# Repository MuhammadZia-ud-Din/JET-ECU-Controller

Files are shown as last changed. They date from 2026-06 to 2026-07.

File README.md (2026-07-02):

# JET ECU Controller

A custom Engine Control Unit (ECU) for monitoring and controlling a small JET engine during ground testing.

The system consists of STM32F103C8T6 firmware and a Python GUI dashboard connected over serial.

---

## Repository Structure

```
JET ECU Firmware/                    — Active firmware (STM32CubeIDE + FreeRTOS)
├── Core/Src/main.c                  — All application code (FreeRTOS tasks, serial protocol)
├── Core/Inc/main.h                  — Pin definitions
└── JET_ECU_Project_Documentation.docx — Full project documentation

JET ECU GUI/
└── ECU GUI.py                       — Python dashboard GUI

JET_ECU_V1.0/
└── JET_ECU_V1.0.ino                 — Arduino firmware
```

---

## Firmware

The active firmware runs on **FreeRTOS (CMSIS-RTOS v2)** with four concurrent tasks:

| Task | Priority | Rate | Role |
|---|---|---|---|
| ThrottleTask | AboveNormal | 200 ms | RC PWM reading, spike filter, 0–100% output |
| VoltageTask | Normal | ~756 ms | Battery voltage (256-sample avg), MCU temperature |
| FETReportTask | Normal | 200 ms | Reports all 6 FET states over serial |
| SerialRxTask | High | Event | Parses incoming commands from GUI |

Built with **STM32CubeIDE**. All user code is inside `USER CODE BEGIN / END` sections and survives CubeMX regeneration.

---

## Features

- **Dual thermocouple monitoring** — EGT (exhaust) and intake temperature via MAX31855
- **Battery voltage** — 12-bit ADC, 256-sample averaging, two-point linear calibration (5V/24V anchors), up to 26V
- **RC throttle input** — GPIO pulseIn via DWT counter, default calibration 1540–2000 µs → 0–100%
- **ESC PWM output** — throttle % mapped 1:1 onto a 1000–2000 µs pulse on PA10 (TIM1_CH3) at 50 Hz, driving a BLDC ESC
- **6-channel FET control** — Toggle individual FETs or use ALL HIGH / ALL LOW group control
- **MCU temperature** — On-chip die temperature sensor
- **Python GUI** — Left: 2×2 gauge grid (Throttle, Tachometer, ESC PWM Output, Battery Voltage). Right: individually-boxed TC1/TC2/MCU temperature graphs, 4×2 FET grid, serial log. Plus Emergency Stop and USB-TTL disconnect detection.

---

## Hardware

| Item | Detail |
|---|---|
| MCU | STM32F103C8T6 (Blue Pill), 64 MHz |
| Thermocouple amplifiers | MAX31855 × 2 (SPI1 + SPI2) |
| RC receiver | R12DS — CH3 PWM signal to PA0 (GPIO Input) |
| ESC output | PA10 (TIM1_CH3), 1000–2000 µs pulse @ 50 Hz, mapped from RC throttle |
| Serial link | UART2 (PA2/PA3) via USB-TTL adapter at 115200 baud |
| Battery input | Up to ~26V via 39K + 5.6K voltage divider on PA1 |

---

## GUI Requirements

```
pip install pyserial
```

Python 3 with `tkinter` (included in standard Python install). No internet required at runtime.

---

## Quick Start

1. Open `JET ECU Firmware/` in STM32CubeIDE and flash to the Blue Pill
2. Connect USB-TTL adapter to PA2 (TX) and PA3 (RX), share GND
3. If powering the board from the battery/supply rather than USB, run a **dedicated, always-connected ground wire** from the battery's negative terminal straight to the Blue Pill's GND pin — independent of the USB-TTL cable. Without it, unplugging/replugging the USB-TTL adapter can leave GND floating momentarily and cause serial glitches (also required for accurate battery voltage sensing — see Calibration in the project docs).
4. Run `ECU GUI.py`
5. Select COM port, set baud to 115200, click CONNECT
6. Throttle works immediately — use **SET RC** only if you need to fine-tune to your transmitter

---

## Serial Protocol

| Direction | Format | Example |
|---|---|---|
| Firmware → PC | `THR: xxx` | `THR: 75` |
| Firmware → PC | `PWM: xxx` | `PWM: 75`  (ESC output %, mirrors THR) |
| Firmware → PC | `TC1: x.x C  \|  TC2: x.x C` | `TC1: 245.5 C  \|  TC2: 32.1 C` |
| Firmware → PC | `Raw: xxxx V_ADC: x.xxx V V_BATT: xx.xx V` | `V_BATT: 23.85 V` |
| Firmware → PC | `MCU: xx.x C` | `MCU: 24.4 C` |
| Firmware → PC | `FET:x,x,x,x,x,x` | `FET:1,0,0,0,0,0` |
| PC → Firmware | `FETn:1` / `FETn:0` | `FET3:1` |
| PC → Firmware | `FET_ALL:1` / `FET_ALL:0` | All 6 FETs HIGH or LOW |
| PC → Firmware | `CAL_CENTER` / `CAL_FULL` / `CAL_RESET` | RC throttle calibration |

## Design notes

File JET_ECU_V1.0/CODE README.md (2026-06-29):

# JET ECU V1.0

Firmware for a custom Engine Control Unit (ECU) designed to monitor and control a JET engine during testing. Built for the STM32F103C8T6 (Blue Pill).

---

## Hardware

| Component | Details |
|---|---|
| MCU | STM32F103C8T6 (Blue Pill) |
| Serial | UART2 via TTL adapter (PA2=TX, PA3=RX) at 115200 baud — bidirectional |

---

## Pin Map

| Function | Pin | Notes |
|---|-----|---|
| Thermocouple 1 SCK | PA5 | EGT / Exhaust — MAX31855 software SPI |
| Thermocouple 1 SO | PA6 | |
| Thermocouple 1 CS | PB0 | |
| Thermocouple 2 SCK | PB13 | Intake / Ambient — MAX31855 software SPI |
| Thermocouple 2 SO | PB14 | |
| Thermocouple 2 CS | PB12 | |
| Battery Voltage | PA1 | Voltage divider: 39K + 5.6K, max input ~24V |
| RC PWM Input | PA0 | R12DS CH3 signal wire — standard 1000–2000µs PWM |
| RPM Sensor | PC14 | Future pulse-counting input (not yet implemented) |
| FET 1 | PB6 | |
| FET 2 | PB5 | |
| FET 3 | PB9 | |
| FET 4 | PB8 | |
| FET 5 | PB4 | |
| FET 6 | PB7 | |
| MCU Temperature | Internal | ADC channel 16 — die temperature sensor |

---

## Libraries

- `Adafruit_MAX31855` — thermocouple temperature reading
- `HardwareSerial` — UART2 serial communication

---

## What is Implemented

### Battery Voltage (PA1)
- 12-bit ADC with 64-sample averaging for noise reduction
- Voltage divider scaling: 39K + 5.6K resistors
- Calibration factor (0.9905) applied to correct ~1% gain error from VDDA/resistor tolerance
- Accuracy: within ±0.05V across 16V–24V input range
- Reported every 500ms

### Thermocouple Reading (TC1 + TC2)
- TC1 reads exhaust gas temperature (EGT) via MAX31855
- TC2 reads intake / ambient temperature via MAX31855
- NaN fault handling — returns 0.0 on sensor fault or open circuit
- Reported every 250ms

### FET Outputs (PB4–PB9)
- All 6 FET pins configured as outputs, driven LOW at startup (safe state)
- Accepts real-time toggle commands from the GUI over serial: `FET1:1` / `FET1:0`
- Reports all 6 FET states every 200ms: `FET:1,0,0,0,0,0`

### RC Throttle Input (PA0)
- Reads standard RC PWM signal from R12DS receiver CH3 pin
- Pulse width range: 1000–2000µs mapped to 0–100% throttle
- Spike rejection: rejects any reading that jumps more than 400µs from last valid
- Hold-last-valid: maintains last known value; resets to 0 only after 500ms signal loss
- Calibration via GUI: SET RC wizard captures center and full-throttle positions
- Reported every 200ms as `THR: xxx`

### MCU Internal Temperature
- Reads the STM32F103 on-chip die temperature sensor (ADC channel 16)
- Calibrated V25 = 1.58V, slope = 4.3 mV/°C
- Accuracy: ±2–3°C (sensor varies chip-to-chip; value reflects die temperature, not ambient)
- Reported every 1000ms

---

## Serial Interface

Connect a USB-TTL adapter to PA2 (TX) and PA3 (RX) at **115200 baud**.

### Output (firmware → PC)

```
JET ECU V1.0 Ready
TC1: 245.5 C  |  TC2: 32.1 C
Raw: 3741    V_ADC: 3.014 V    V_BATT: 24.01 V
THR: 75
MCU: 24.4 C
FET:1,0,0,0,0,0
```

### Input (PC → firmware)

| Command | Action |
|---|---|
| `FET1:1` | Turn FET 1 HIGH |
| `FET1:0` | Turn FET 1 LOW |
| `FET2:1` … `FET6:0` | Same for FETs 2–6 |
| `CAL_CENTER` | Sample RC center position (hold stick at center first) |
| `CAL_FULL` | Sample RC full throttle position (push stick to full first) |
| `CAL_RESET` | Clear calibration — throttle returns 0 until recalibrated |

---

## GUI Dashboard

A Python-based ground station (`JET ECU GUI/ECU GUI.py`) connects over serial and displays all channels in real time:

- **THROTTLE gauge** — RC input 0–100%
- **TACHOMETER gauge** — RPM sensor 0–50,000 (PC14, pending implementation)
- **Battery voltage** circular gauge
- **Vertical thermometers** for TC1 (EGT), TC2 (Intake), and MCU temperature
- **FET panel** — live status LEDs and toggle buttons (layout: 1/3/5 top, 2/4/6 bottom)
- **SET RC / RESET RC** calibration buttons
- Serial log with CLEAR button

---

## What is Pending

- [ ] RPM sensor (PC14) — pulse counting via external interrupt, output `RPM: xxx`

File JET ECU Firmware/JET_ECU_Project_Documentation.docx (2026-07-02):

JET ECU Controller

Project Documentation — Design, Implementation & Status

Date: July 02, 2026

1. Project Overview

The JET ECU Controller is a custom Engine Control Unit (ECU) designed to monitor and control a small JET (turbine) engine during laboratory ground testing. The system connects a microcontroller-based hardware unit to a PC-based graphical dashboard over a serial link, enabling real-time telemetry display and manual actuation of engine components.

The project targets a low-cost, self-contained solution that can run fully offline on any Windows/Linux/macOS PC with Python installed — no cloud connectivity or proprietary software required.

2. Requirements & Goals

2.1 Functional Requirements

ID | Requirement
FR-01 | Monitor two thermocouple temperatures (exhaust EGT + intake ambient) in real time.
FR-02 | Monitor battery / supply voltage up to 26 V with ±0.1 V accuracy.
FR-03 | Read RC receiver throttle PWM signal and map it to 0–100 % throttle.
FR-04 | Control six high-side FET outputs individually or all at once (ALL HIGH / ALL LOW) from the GUI.
FR-05 | Display MCU die temperature as a system health indicator.
FR-06 | Transmit all sensor data to the PC GUI over UART at 115200 baud.
FR-07 | Accept individual FET toggle commands, group FET commands, and RC calibration commands from the GUI.
FR-08 | Provide a PC-side dashboard with live gauges — no internet required.
FR-09 | RC throttle must work immediately on power-on using hardcoded default calibration values.

2.2 Non-Functional Requirements

- Real-time telemetry update rates: throttle every 200 ms, voltage every 500 ms, temperature every 250 ms.
- Spike rejection on RC throttle: reject any single reading that jumps more than 400 µs from the last valid reading.
- Hold-last-valid on RC signal loss: maintain last known throttle value; reset to 0 % only after 500 ms of no signal.
- Voltage measurement must survive power-on noise (raw-count zero-offset calibration).
- GUI must work fully offline with standard Python 3 and pyserial.
- All firmware code must survive CubeMX code regeneration (placed in USER CODE sections only).

3. Hardware

3.1 Components

Component | Part / Type | Notes
Microcontroller | STM32F103C8T6 | Blue Pill board, 72 MHz max, 64 MHz used (HSI × PLL)
Thermocouple Amp ×2 | MAX31855 | SPI interface, ±2 °C accuracy, open-circuit detection
RC Receiver | R12DS | CH3 PWM output, 1000–2000 µs pulse width at 50 Hz
Serial Adapter | USB-TTL (CP210x) | Connects PA2/PA3 to PC USB port at 115200 baud
FET Driver ×6 | High-side FETs | GPIOB-driven, active-HIGH control signal
Voltage Divider | 39 kΩ + 5.6 kΩ | Scales battery input (up to ~26 V) to ADC range (0–3.3 V)

3.2 Pin Map

Pin | Function | Details
PA0 | RC PWM Input | R12DS CH3 signal — digital GPIO_Input NOPULL, pulseIn via DWT cycle counter
PA1 | Battery Voltage ADC | 39 kΩ + 5.6 kΩ divider, ADC1 CH1, 12-bit, DMA circular
PA2 | UART2 TX | Serial output to PC (115200 baud)
PA3 | UART2 RX | Serial input from PC (115200 baud, DMA Normal mode + IDLE detection)
PA5 | TC1 SCK | MAX31855 #1 clock (EGT / Exhaust), SPI1
PA10 | ESC PWM Output | TIM1_CH3, 1000–2000 µs pulse @ 50 Hz, mapped 1:1 from RC throttle %
PA6 | TC1 SO | MAX31855 #1 data out, SPI1
PB0 | TC1 CS | MAX31855 #1 chip select
PB13 | TC2 SCK | MAX31855 #2 clock (Intake / Ambient), SPI2
PB14 | TC2 SO | MAX31855 #2 data out, SPI2
PB12 | TC2 CS | MAX31855 #2 chip select
PB4 | FET 5 | High-side FET #5 control, active HIGH
PB5 | FET 2 | High-side FET #2 control, active HIGH
PB6 | FET 1 | High-side FET #1 control, active HIGH
PB7 | FET 6 | High-side FET #6 control, active HIGH
PB8 | FET 4 | High-side FET #4 control, active HIGH
PB9 | FET 3 | High-side FET #3 control, active HIGH
PC14 | RPM Sensor Input | Future: pulse-counting via external interrupt (not yet implemented)
INT | MCU Temperature | ADC1 CH16 internal temperature sensor — die temperature

4. Software Architecture

The firmware runs on FreeRTOS (CMSIS-RTOS v2) with four application tasks running concurrently. The PC dashboard is a single-file Python script using tkinter for the GUI and pyserial for communication.

4.1 Firmware Tasks

Task | Priority | Period | Responsibility
ThrottleTask | AboveNormal | 200 ms | Reads RC PWM via GPIO polling (pulseIn_us), applies spike filter and hold-last-valid logic, maps to 0–100 % throttle, drives the ESC PWM output (TIM1_CH3), sends THR: and PWM: output.
VoltageTask | Normal | ~756 ms | Averages 256 ADC DMA samples (1 ms apart) for battery voltage, applies two-point linear calibration. Reads MCU die temp every ~1512 ms.
FETReportTask | Normal | 200 ms | Reads current GPIO state of all 6 FET pins and reports FET:x,x,x,x,x,x over serial.
SerialRxTask | High | Event | Waits on UART IDLE semaphore, parses incoming commands (FETn:x, FET_ALL:x, CAL_CENTER, CAL_FULL, CAL_RESET), executes and responds.

4.2 FreeRTOS Configuration

Parameter | Value | Notes
Heap size | 8192 bytes | Set via .ioc — sufficient for 4 tasks + mutexes + semaphores
Application task stack | 1024 bytes (256×4) | Each of the 4 tasks — sized for snprintf + HAL calls
Tick rate | 1000 Hz (1 ms) | Standard FreeRTOS tick
UART TX method | Blocking HAL_UART_Transmit + mutex | DMA TX caused deadlocks; blocking is safe and simple
UART RX method | DMA Normal + IDLE detection | HAL_UARTEx_ReceiveToIdle_DMA; half-transfer interrupt disabled; semaphore on each line received
ADC1 DMA | Circular, 2-channel scan | Continuously fills adc_buf[0]=battery, adc_buf[1]=MCU temp
RC timing | DWT cycle counter (64 cycles = 1 µs) | Measures pulse width without a hardware timer; 50 ms timeout per call
TIM1 (ESC PWM) | PSC=63, ARR=19999 | 1 MHz counter, 20 ms/50 Hz period; CCR value in µs directly matches RC/ESC pulse convention

5. Implemented Features

5.1 Battery Voltage Measurement

- Voltage divider: 39 kΩ (R1) + 5.6 kΩ (R2) scales battery voltage to ADC input range (max ~26 V).
- ADC1 CH1 (PA1) reads in 12-bit DMA circular mode alongside MCU temperature on CH16.
- 256-sample averaging with 1 ms delay between samples (increased from an initial 64) — halves report-to-report ADC jitter with no added lag, since each report is computed independently (no memory carried between reports, so a real voltage change still shows on the next report).
- Two-point direct linear interpolation between two known (raw, voltage) points — no forced "0 V" anchor, since that raw value drifts whenever the sense line’s ground reference changes (e.g. powering the board from the battery supply vs. from USB):
- VBATT_RAW_LO = 770 at VBATT_MV_LO = 5000 mV (low anchor point)
- VBATT_RAW_HI = 3710 at VBATT_MV_HI = 24000 mV (high anchor point)
- Formula: V_batt (mV) = MV_LO + (raw − RAW_LO) × (MV_HI − MV_LO) / (RAW_HI − RAW_LO)
- VBATT_RAW_FLOOR = 250 → raw ≤ 250 is treated as no battery connected → reports 0.00 V
- Anchored on the widest available voltage separation (5 V / 24 V) for best accuracy — validated against 10 V and 20 V measurements, both within ±0.02 V of actual.
- Serial output: Raw: 3608 V_ADC: 2.907 V V_BATT: 24.00 V (every ~756 ms)
- Calibration constants in one #define block in firmware — easy to update per board.

5.2 RC Throttle Input

- RC receiver R12DS CH3 output connected to PA0 as digital GPIO_Input (no pull resistor).
- PA0 must NOT be configured as ADC input — RC PWM is a 3.3–5 V square wave, not an analog signal.
- pulseIn_us() function uses the DWT cycle counter (64 cycles = 1 µs) to time the HIGH pulse.
- 50 ms timeout per measurement call — covers the full 20 ms RC period plus FreeRTOS jitter.
- Spike filter: reading rejected if it differs from last valid by more than 400 µs.
- Hold-last-valid: maintains last good value; resets to center only after 500 ms of signal loss.
- Default calibration values (stored in firmware, active from first power-on):
- rc_pw_min = 1540 µs → 0 % throttle reference (measured neutral position on this board)
- rc_pw_max = 2000 µs → 100 % throttle reference (full throw)
- Throttle works immediately on power-on without requiring user calibration.
- GUI-driven recalibration (optional — use if defaults do not match your transmitter):
- CAL_CENTER → averages 10 pulses at center position → overwrites 0 % reference in RAM
- CAL_FULL → averages 10 pulses at full throw → overwrites 100 % reference in RAM
- CAL_RESET → clears RAM calibration to 0/0; throttle reads 0 % until SET RC is run again
- Values outside calibrated range are clamped (below min = 0 %, above max = 100 %).
- RAM calibration is lost on power cycle — defaults (1540/2000) are restored automatically.
- Serial output: THR: 75 (every 200 ms, integer 0–100)

5.3 ESC PWM Output (BLDC Motor Control)

- Drives an ESC (Electronic Speed Controller) for a BLDC motor via a standard RC-style PWM signal on PA10 (TIM1_CH3).
- TIM1 configured for a 1 MHz counter (Prescaler=63) with a 20000-count period (Period/ARR=19999) → 20 ms period = 50 Hz, the standard RC/ESC signal rate.
- Because the counter runs at 1 MHz, the CCR (pulse) register value in counts equals the pulse width in microseconds directly — no extra scaling math needed.
- ThrottleTask maps the same 0–100 % throttle value used for THR: onto the pulse width: pwm_us = 1000 + (throttle × 1000 / 100), giving the standard 1000 µs (0 %) to 2000 µs (100 %) ESC convention.
- PWM output starts at boot (1000 µs, armed-and-idle) via HAL_TIM_PWM_Start(), before the RTOS scheduler takes over — the ESC sees a valid idle signal immediately rather than a floating pin.
- Firmware reports the mapped percentage every 200 ms: PWM: 75 (mirrors THR: since the mapping is currently 1:1; reported separately so the GUI/log reflect the actual ESC command being sent, not just the RC input reading).

5.4 FET Outputs

- Six FET control pins on GPIOB (FET1=PB6, FET2=PB5, FET3=PB9, FET4=PB8, FET5=PB4, FET6=PB7).
- All pins initialised LOW (safe off state) at startup.
- Individual control: GUI sends FETn:1 or FETn:0 (n = 1–6) to toggle any single FET.
- Group control: GUI sends FET_ALL:1 (all 6 FETs HIGH) or FET_ALL:0 (all 6 FETs LOW).
- Firmware confirms group commands: responds FET_ALL:1 or FET_ALL:0 over UART.
- Firmware reports all six states every 200 ms: FET:1,0,0,0,0,0
- GUI FET panel layout — 4 rows × 2 columns:
- Row 0: FET 1 | FET 2 Row 1: FET 3 | FET 4 Row 2: FET 5 | FET 6
- Row 3: ALL HIGH (green LED) | ALL LOW (red LED)
- Each cell shows: coloured LED (green=ON, red=OFF), label, state text, and action button.
- ALL HIGH / ALL LOW buttons update all six GUI LEDs immediately on click.

5.5 Thermocouple Reading (TC1 + TC2)

- Two MAX31855 thermocouple amplifiers connected via hardware SPI (SPI1 and SPI2).
- TC1 on SPI1 (PA5/PA6/PB0) monitors exhaust gas temperature (EGT).
- TC2 on SPI2 (PB13/PB14/PB12) monitors intake / ambient temperature.
- Open-circuit / fault detection: NaN returned on fault → reported as 0.0 °C.
- Serial output: TC1: 245.5 C | TC2: 32.1 C (every 250 ms)

5.6 MCU Internal Temperature

- STM32F103 internal temperature sensor on ADC1 CH16, sampled in the same DMA scan as battery voltage.
- Calibration: V25 = 1.58 V, slope = 4.3 mV/°C (empirically measured; datasheet typical: V25=1.43 V).
- Accuracy: ±2–3 °C — useful as a thermal health indicator for the MCU, not for ambient temperature.
- Serial output: MCU: 24.4 C (every 1000 ms)

5.7 PC Dashboard (Python GUI)

- Single Python file (ECU GUI.py), no installation beyond Python 3 + pyserial.
- Connects to any available COM port at 115200 baud; auto-detects and parses all telemetry lines.
- Two-column layout — left: 2×2 gauge grid; right: stacked temperature / FET / log panel.
- Left column, row 0: THROTTLE gauge | TACHOMETER gauge
- Left column, row 1: ESC PWM OUTPUT gauge | BATTERY VOLTAGE gauge
- All four are 290 px needle dials with a digital value readout on the dial face, in the blank 90° wedge below the pivot where the sweep and tick labels leave genuinely empty space — avoids the value overlapping the needle, and needs no separate box or border.
- Right column, top: TC1 / TC2 / MCU temperature graphs, each in its own bordered card, evenly justified across the column width (equal-weighted grid columns) so there is no empty gap.
- Right column, middle: FET panel, 4 rows × 2 columns (FET1/FET2, FET3/FET4, FET5/FET6, ALL HIGH/ALL LOW). Each cell: coloured LED, label, HIGH/LOW state text, action button on the right.
- Right column, bottom: serial log — confined to the right column's width (not the full window), height reduced to keep the overall window height close to the left gauge column's height.
- Emergency Stop button (top-right of the connection bar) — forces all 6 FETs LOW immediately, independent of the ALL LOW button in the FET panel, always visible regardless of scroll position.
- USB-TTL disconnect detection — if the serial adapter is physically removed while connected, the reader thread detects the read failure and automatically resets the GUI to DISCONNECTED (status, button, all gauges, all FET states) instead of freezing on stale data.
- RC calibration: SET RC button → step-by-step wizard (center position → full throw).
- RESET RC: clears RAM calibration; user must redo SET RC to restore custom mapping.
- All displays reset to zero on disconnect (manual or automatic).

6. Serial Protocol

Connection: 115200 baud, 8N1, UART2 (PA2 = TX, PA3 = RX) via USB-TTL adapter.

6.1 Firmware → PC Telemetry

Message | Rate | Description
JET ECU V1.0 Ready | Once on boot | Boot confirmation banner
TC1: 245.5 C | TC2: 32.1 C | Every 250 ms | Thermocouple temperatures in °C
Raw: 3741 V_ADC: 3.014 V V_BATT: 24.01 V | Every 500 ms | Raw ADC count, divider output, calibrated battery voltage
THR: 75 | Every 200 ms | RC throttle percentage (0–100, integer)
PWM: 75 | Every 200 ms | ESC PWM output percentage (mirrors THR — the actual mapped ESC command)
MCU: 24.4 C | Every ~1512 ms | MCU die temperature in °C
FET:1,0,0,0,0,0 | Every 200 ms | State of FET1–FET6 (1=ON, 0=OFF, comma-separated)

6.2 PC → Firmware Commands

Command | Action
FET1:1 | Turn FET 1 ON (drive HIGH)
FET1:0 | Turn FET 1 OFF (drive LOW)
FET2:1 … FET6:0 | Same for FETs 2 through 6
FET_ALL:1 | Set ALL six FETs HIGH simultaneously. Firmware responds: FET_ALL:1
FET_ALL:0 | Set ALL six FETs LOW simultaneously. Firmware responds: FET_ALL:0
CAL_CENTER | Sample 10 RC pulses at stick center; sets 0 % throttle reference in RAM. Responds: CAL_CENTER:1540
CAL_FULL | Sample 10 RC pulses at full throw; sets 100 % throttle reference in RAM. Responds: CAL_FULL:2000
CAL_RESET | Clear RAM calibration to 0/0; throttle reads 0 % until SET RC is run. Responds: CAL_RESET:OK

7. Calibration Procedures

7.1 Battery Voltage Calibration

Required whenever the supply/ground path changes (e.g. switching between powering the board from USB vs. from the battery/supply directly) — the raw ADC baseline shifts with the ground reference even though the underlying voltage-to-raw-count slope stays the same. Requires a known-accurate bench supply or multimeter.

- Step 1: Power the board exactly as it will be used during testing (this affects the ground reference).
- Step 2: Apply a known low voltage (e.g. 5.00 V) to the battery input. Note the "Raw: xxxx" value → LO point.
- Step 3: Apply a known high voltage (e.g. 24.00 V). Note the "Raw: xxxx" value → HI point.
- Step 4: Use the widest voltage separation available — it minimizes calibration error.
- Step 5: Set VBATT_RAW_LO / VBATT_MV_LO and VBATT_RAW_HI / VBATT_MV_HI from those two readings.
- Step 6: Rebuild and flash. Cross-check against one or two intermediate voltages to confirm accuracy.

Board measurements (2026-07-02, direct-supply powered, re-checked): 5.00 V → Raw 770, 24.00 V → Raw 3710. Anchored on the widest available separation (5 V/24 V).

7.2 Grounding for Reliable UART Operation

When the board is powered by the battery/supply instead of USB, the USB-TTL adapter's GND wire may be the only path tying the PC's ground and the board's ground together. Unplugging/replugging the TTL adapter in that condition can leave GND floating for a moment during the connector mating transition, which can glitch the UART RX line or briefly reset the MCU.

- Run a separate, permanently-connected ground wire from the battery's negative terminal directly to the Blue Pill's GND pin, independent of whichever wire is currently supplying power to the board.
- This ground wire should remain connected at all times, regardless of which power source (USB or battery) is active, or whether the USB-TTL adapter is plugged in.
- With a dedicated ground path in place, the TTL adapter's TX/RX/GND can be safely unplugged and replugged without disturbing the board's ground reference.
- This is the same underlying requirement as accurate battery voltage sensing (Section 5.1) — both the ADC divider and the UART need a ground reference that does not depend on which cable is currently plugged in.

7.3 RC Throttle Calibration (optional — GUI-driven)

Firmware ships with default values rc_pw_min = 1540 µs (0 %) and rc_pw_max = 2000 µs (100 %). These match the measured neutral and full-throw positions on this board and allow the throttle to function immediately without user calibration. Use SET RC only if the defaults do not match your transmitter or after running RESET RC.

- Step 1: Power on the RC transmitter and receiver. Confirm signal is present (THR: will start printing).
- Step 2: Hold the throttle stick at the centre/idle position.
- Step 3: In the GUI, click SET RC → OK at Step 1 prompt. Firmware averages 10 pulses → stores as 0 % reference.
- Step 4: Push the throttle stick to full throttle position.
- Step 5: Click OK at Step 2 prompt. Firmware averages 10 pulses → stores as 100 % reference.
- Step 6: THR: value now tracks stick position from 0 to 100.
- Step 7: Click RESET RC at any time to clear the RAM calibration; throttle returns 0 % until SET RC is re-run.

Note: SET RC and RESET RC operate on RAM only — values are lost on power cycle. Firmware defaults (1540 / 2000) are automatically restored at next boot.

8. Issues Encountered and Resolutions

Issue: UART not printing anything

Root Cause: DMA transmit + binary semaphore pattern caused deadlock when task stacks were too small. Stack overflow corrupted the semaphore state.

Resolution: Replaced DMA TX with blocking HAL_UART_Transmit protected by a mutex. Increased all application task stacks from 512 bytes to 1024 bytes.

Issue: RC calibration command stuck — firmware froze on CAL_CENTER

Root Cause: UART RX DMA was configured in Circular mode. In this mode the DMA transfer size accumulates across commands, so subsequent commands were not parsed correctly and the firmware appeared to hang.

Resolution: Changed UART2 RX DMA to Normal mode in the .ioc configuration. The DMA restarts cleanly after each line received via the IDLE callback.

Issue: Battery voltage fluctuating wildly on power-on (0 – 3 V at 0 V actual)

Root Cause: Firmware was reading a single DMA ADC sample capturing high-frequency noise. Additionally the ADC had a zero-offset (~0.15–0.17 V at 0 V actual input).

Resolution: Implemented 64-sample averaging with 1 ms delay between samples. Added a raw-count zero-offset calibration constant (VBATT_RAW_ZERO = 190) to clamp the noise floor to 0.00 V.

Issue: Battery voltage showing ~0.38 V at 0 V input after initial calibration attempt

Root Cause: Initial calibration constants were derived from single-sample (non-averaged) measurements. After enabling 64-sample averaging the ADC baseline shifted — zero-offset raw count changed from ~55 to ~183, making old constants invalid.

Resolution: Switched to a raw-count two-point calibration formula that bypasses the resistor-divider intermediate calculation entirely. Constants updated from board measurements: VBATT_RAW_ZERO = 190, VBATT_RAW_CAL = 3923 at 24.00 V.

Issue: RC throttle always reading 0 % (THR: 0) regardless of stick position

Root Cause: PA0 was configured as ADC input. ADC showed ~0.3 V constant because it was averaging the 7.5 % duty-cycle PWM (1500 µs HIGH out of 20 ms period), not seeing the individual pulses.

Resolution: Removed ADC2 from .ioc; reconfigured PA0 as GPIO_Input. Implemented pulseIn_us() using DWT cycle counter to time HIGH pulses directly. Timeout increased to 50 ms to account for FreeRTOS scheduling jitter. Confirmed 1530–1950 µs signal via debug print. Throttle now maps correctly 0–100 %.

Issue: RC throttle stuck at 0 % after CAL_CENTER (THR: 0 with valid signal)

Root Cause: sample_rc_pw() was using 20 samples with a tight valid-range check; some samples failed the 900–2100 µs gate, causing the average to come out 0, setting rc_pw_min = 0 and rc_pw_max = 0.

Resolution: Reduced to 10 samples (faster, less chance of gating failure); verified pulseIn_us returns valid values via debug print. Throttle mapping now works correctly across full range.

Issue: Battery voltage showing a constant ~1.6 V offset after switching to direct-supply power (24.00 V actual read as 22.40 V; 20.00 V actual read as 18.40 V — same absolute gap at both points, confirming an offset, not a gain error)

Root Cause: The old VBATT_RAW_ZERO/VBATT_RAW_CAL constants were calibrated while the board was powered via USB. Powering the Blue Pill directly from the battery/supply instead changed the ADC sense line’s ground reference, shifting the raw ADC baseline for every voltage by a constant amount — the "0 V anchor" the old formula relied on no longer matched reality.

Resolution: Replaced the zero-anchored formula with a direct two-point linear interpolation between two real, non-extrapolated measurements (5.00 V → Raw 678, 24.00 V → Raw 3608), which is immune to this kind of ground-reference shift since it does not assume any particular raw value corresponds to exactly 0 V. Validated against 10 V/20 V measurements — both within ±0.02 V of actual.

Issue: Residual ~0.10 V report-to-report fluctuation in V_BATT even after correct calibration

Root Cause: The 64-sample block average still let through some ADC/supply noise between reports; a first attempt at fixing it with a 10-report moving average smoothed the display but made it react to genuine voltage changes ~5.6 s slower — rejected as unacceptable lag.

Resolution: Increased the per-report oversampling window from 64 to 256 samples instead. This halves jitter via the same block average (√(256/64) ≈ 2×) but carries no memory between reports, so a real voltage change still shows up on the very next report — no added lag, unlike the moving-average approach.

Issue: FET outputs turn HIGH then immediately revert to LOW on their own — happens on every individual FET and on FET_ALL:1 identically; no MCU reboot banner in the log

Root Cause: Firmware code was verified clean (no rogue GPIO write path resets the pins, individual and group commands share correct, identical logic, pin mapping between write and readback is consistent). Root-caused via staged testing: worked correctly on USB-TTL power alone, and on battery power with the TTL still connected — but failed specifically after unplugging and replugging the TTL adapter while the board ran on battery power. With no separate ground wire between the battery and the board, the TTL's GND wire was the only path tying the PC's ground and the board's ground together; unplugging it left GND floating momentarily, and the connector pins not mating simultaneously on replug caused a transient on RX/GND that glitched the UART or briefly reset the MCU (which re-runs the boot-time GPIO init that forces all FET pins LOW).

Resolution: Diagnosed root cause; recommended fix is a dedicated, permanently-connected ground wire from the battery's negative terminal directly to the Blue Pill's GND pin, independent of the USB-TTL cable — see Section 7.2. Same class of fix as the battery-voltage ground-reference issue above, applied to the UART connection instead of the ADC sense line. Pending field confirmation that the dedicated ground wire eliminates the issue.

9. Current Status

9.1 Completed

- ✓ Battery voltage — 256-sample averaged, two-point linear calibration (5V/24V anchors), accurate to ±0.02 V
- ✓ RC throttle — GPIO pulseIn, default cal (1540/2000 µs), spike filter, hold-last-valid, 0–100 % output
- ✓ ESC PWM output — throttle % mapped 1:1 onto TIM1_CH3 (PA10), 1000–2000 µs @ 50 Hz, drives a BLDC ESC
- ✓ Six FET outputs — individual toggle + ALL HIGH / ALL LOW group control
- ✓ FET group commands — FET_ALL:1 and FET_ALL:0 iterate all 6 pins in firmware
- ✓ MCU die temperature — internal ADC channel, reported every ~1512 ms
- ✓ Thermocouple TC1 + TC2 (MAX31855) — temperature reporting every 250 ms via SPI
- ✓ UART telemetry — all channels on UART2, 115200 baud, DMA RX + blocking TX
- ✓ FreeRTOS multi-task firmware — four concurrent tasks with mutex-protected UART
- ✓ PC Python GUI — 2×2 left gauge grid (Throttle/Tach/PWM/Voltage), individually-boxed temp graphs, 4×2 FET panel, Emergency Stop, USB-TTL disconnect detection, RC calibration wizard, serial log

9.2 Pending

- ○ RPM Sensor (PC14) — Pulse-counting via external interrupt on PC14. Output format: RPM: xxxxx at 1000 ms intervals. GUI tachometer gauge is already implemented and waiting for this data.
- ○ Battery voltage — hardware-level ripple — If jitter is still noticeable after the 256-sample software averaging, the remaining cause is likely real analog ripple/noise on the PA1 sense line rather than something software averaging alone can remove. A small filter capacitor (100 nF–1 µF) from PA1 to GND would filter it at the source.
- ○ Thermocouple port to CubeIDE — TC1/TC2 SPI reading is currently only in the original Arduino firmware. The CubeIDE firmware has SPI1/SPI2 configured but the MAX31855 read routine has not yet been ported to the STM32 HAL SPI API.
- ○ FET outputs reverting to LOW on battery power — Root cause diagnosed as a missing dedicated ground wire between the battery and the board (see Section 8 issue and Section 7.2). Fix identified but not yet confirmed in the field — verify the boot banner no longer reprints and FETs hold state after adding the ground wire.

10. Key Values Reference

Parameter | Value | Notes
RC PWM default min (0 %) | 1540 µs | Hardcoded firmware default — measured neutral on this board
RC PWM default max (100 %) | 2000 µs | Hardcoded firmware default — standard RC full throw
RC pulse valid range | 900–2100 µs | Readings outside this range are discarded by ThrottleTask
RC spike filter | 400 µs max jump | Per sample; rejects mechanical bounce and EMI spikes
RC signal-loss timeout | 500 ms | After this, throttle resets to hold-last-valid then 0 %
RC pulseIn timeout | 50 ms | Covers 20 ms RC period + FreeRTOS scheduling jitter margin
CAL_CENTER / CAL_FULL samples | 10 pulses averaged | RAM-only; lost on power cycle; defaults restored at boot
VBATT_RAW_LO / VBATT_MV_LO | 770 / 5000 mV | Low calibration anchor (measured, direct-supply powered)
VBATT_RAW_HI / VBATT_MV_HI | 3710 / 24000 mV | High calibration anchor (measured, direct-supply powered)
VBATT_RAW_FLOOR | 250 | Raw ADC count at/below which output clamps to 0.00 V (no battery)
Voltage divider ratio | 44600 / 5600 ≈ 7.96× | 39 kΩ + 5.6 kΩ; max readable ~26 V
ADC resolution | 12-bit (0–4095) | VDDA = 3.3 V; 1 LSB ≈ 0.806 mV
ADC averaging | 256 samples × 1 ms | Total settling time ~256 ms per voltage reading
ESC PWM pulse range | 1000–2000 µs | 0–100 % throttle mapped 1:1 onto standard RC/ESC pulse convention
ESC PWM frequency | 50 Hz (20 ms period) | TIM1: PSC=63 → 1 MHz counter, ARR=19999 → 20 ms period
ESC PWM idle-at-boot | 1000 µs | Set before RTOS scheduler starts — ESC sees a valid signal immediately
MCU clock | 64 MHz | HSI oscillator × PLL; DWT counter: 64 cycles = 1 µs
MCU V25 | 1.58 V | Internal temp sensor V25 (empirically measured; datasheet typical = 1.43 V)
MCU temp slope | 4.3 mV / °C | Internal temperature sensor slope
UART baud rate | 115200 | 8N1, no flow control
FreeRTOS heap | 8192 bytes | Total FreeRTOS heap (set in .ioc)
Task stack size | 1024 bytes | Each of the 4 application tasks

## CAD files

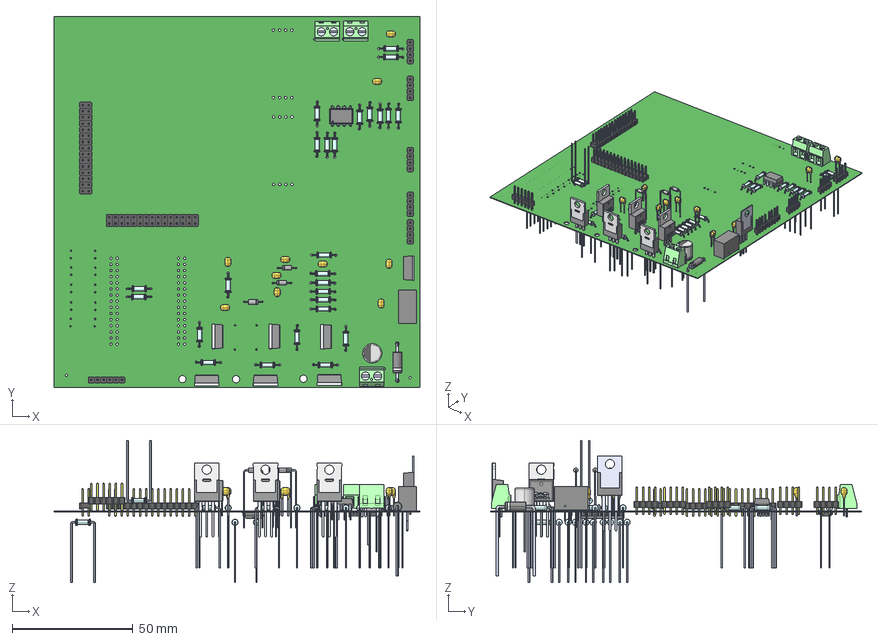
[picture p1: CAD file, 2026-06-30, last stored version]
Faizan Khan Design/JET ENGINE ECU for BLDC motor STM 32f405/JET ECU ver_2.1.step
151.6 x 153.8 x 59.0 mm
MFP-25BRD52-220R x 38
Base014 x 2
Pino029 x 2
Pino030 x 2
Base x 8
Pino1 x 2
Pino2 x 2
Base001 x 8
Pino003 x 8
Pino004 x 3
Base002 x 8
Pino006 x 2
Pino005 x 3
Base003 x 8
Pino008 x 2
Pino007 x 2
Base004 x 3
Pino009 x 2
Pino010 x 2
Base005 x 3
Pino012 x 2
Pino011 x 2
Base006 x 2
Pino013 x 2
Pino014 x 2
Base007 x 2
Pino015 x 2
Pino016 x 2
Base008 x 2
Pino017 x 2
Pino018 x 2
Base009 x 2
Pino019 x 2
Pino020 x 2
Base010 x 2
Pino021 x 2
Pino022 x 2
Base011 x 2
Pino023 x 2
Pino024 x 2
Base012 x 2
Pino025 x 2
Pino026 x 2
Base013 x 2
Pino027 x 2
Pino028 x 2
Body001 (Mirror #1) x 8
XY-plane x 24
X-axis x 24
PG-TO220-3-904_Z8B00198139_V06_3D x 6
Pino x 6
Pino001 x 6
Pino002 x 6
282837-2--3DModel-STEP-269445 x 3
Diode 1N4148 x 3
1N5408
C315C470J1G5TA x 10

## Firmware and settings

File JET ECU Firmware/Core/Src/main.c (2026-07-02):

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
/* Includes ------------------------------------------------------------------*/
#include "main.h"
#include "cmsis_os.h"

/* USER CODE BEGIN Includes */
#include <string.h>
#include <stdio.h>
/* USER CODE END Includes */

/* USER CODE BEGIN PD */

/* ── Battery voltage two-point calibration (raw ADC count based) ─────────────
   Direct linear interpolation between two known (raw, voltage) points —
   no forced "0 V" anchor, since that raw value drifts whenever the sense
   line's ground reference changes (e.g. powering the board from the
   battery supply vs. from USB). Anchoring on two real mid/high-range
   measurements instead is immune to that shift.

   HOW TO RECALIBRATE (if the supply/ground path changes again):
     1. Apply a known low voltage, note "Raw: xxxx" → LO point.
     2. Apply a known high voltage, note "Raw: xxxx" → HI point.
        (Use the widest voltage separation you can — it minimizes error.)
     3. Set the four constants below from those two readings.

   Board measurements (2026-07-02, direct-supply powered, re-checked):
     5.00 V → Raw 770  |  24.00 V → Raw 3710
   Anchored on the widest available separation (5 V / 24 V).                */
#define VBATT_RAW_LO     770UL   /* raw count at VBATT_MV_LO actual voltage */
#define VBATT_MV_LO     5000UL   /* actual voltage at the low calibration point (mV) */
#define VBATT_RAW_HI    3710UL   /* raw count at VBATT_MV_HI actual voltage */
#define VBATT_MV_HI    24000UL   /* actual voltage at the high calibration point (mV) */
#define VBATT_RAW_FLOOR  250UL   /* below this, treat as no battery connected → 0.00 V */

/* USER CODE END PD */

ADC_HandleTypeDef hadc1;
DMA_HandleTypeDef hdma_adc1;

SPI_HandleTypeDef hspi1;
SPI_HandleTypeDef hspi2;
DMA_HandleTypeDef hdma_spi1_rx;
DMA_HandleTypeDef hdma_spi2_rx;

TIM_HandleTypeDef htim1;

UART_HandleTypeDef huart2;
DMA_HandleTypeDef hdma_usart2_rx;
DMA_HandleTypeDef hdma_usart2_tx;

/* Definitions for defaultTask */
osThreadId_t defaultTaskHandle;
const osThreadAttr_t defaultTask_attributes = {
  .name = "defaultTask",
  .stack_size = 128 * 4,
  .priority = (osPriority_t) osPriorityNormal,
};
/* USER CODE BEGIN PV */

/* ── ADC DMA buffer ─────────────────────────────────────────────────────────
   [0] = Battery voltage raw (PA1 / CH1)
   [1] = MCU temperature raw (internal TEMPSENSOR / CH16)
   DMA runs in circular mode — just read these two values anytime.           */
static uint16_t adc_buf[2];

/* ── RC PWM input (PA0, GPIO polling via DWT — matches Arduino pulseIn) ─── */
static uint32_t rc_pw_min        = 1535U;     /* default 0 % position (µs)  */
static uint32_t rc_pw_max        = 1950U;     /* default 100 % position (µs) */
static uint32_t rc_last_pw       = 1500;      /* last accepted pulse width   */
static uint32_t rc_last_valid_ms = 0;         /* kernel tick of last valid PW */
#define RC_MAX_STEP   400U                    /* max µs jump between samples  */
#define RC_TIMEOUT_MS 500U                    /* signal-loss timeout          */

/* ── UART RX ────────────────────────────────────────────────────────────── */
#define RX_BUF_SIZE 64
static uint8_t rx_dma_buf[RX_BUF_SIZE];      /* DMA target (circular)       */
static char    rx_cmd[RX_BUF_SIZE];          /* command copied on IDLE event */

/* ── FET GPIO pin array (index 0=FET1 … 5=FET6, all GPIOB) ────────────── */
static const uint16_t FET_PIN[6] = {
    FET_1_Pin, FET_2_Pin, FET_3_Pin,
    FET_4_Pin, FET_5_Pin, FET_6_Pin
};

/* ── RTOS synchronisation objects ──────────────────────────────────────── */
static osMutexId_t     uart_tx_mutex;   /* one sender at a time              */
static osSemaphoreId_t uart_cmd_sem;    /* signalled by UART RX IDLE ISR     */

/* ── Task handles ───────────────────────────────────────────────────────── */
static osThreadId_t throttleTaskHandle;
static osThreadId_t voltageTaskHandle;
static osThreadId_t fetReportTaskHandle;
static osThreadId_t serialRxTaskHandle;

/* USER CODE END PV */

void SystemClock_Config(void);
static void MX_GPIO_Init(void);
static void MX_DMA_Init(void);
static void MX_ADC1_Init(void);
static void MX_TIM1_Init(void);
static void MX_USART2_UART_Init(void);
static void MX_SPI1_Init(void);
static void MX_SPI2_Init(void);
void StartDefaultTask(void *argument);

/* USER CODE BEGIN PFP */
static void     uart_send(const char *str);
static uint32_t pulseIn_us(GPIO_TypeDef *port, uint16_t pin, uint32_t timeout_us);
static uint32_t sample_rc_pw(uint8_t n);
void ThrottleTask(void *arg);
void VoltageTask(void *arg);
void FETReportTask(void *arg);
void SerialRxTask(void *arg);
/* USER CODE END PFP */

/**
  * @brief  The application entry point.
  * @retval int
  */
int main(void)
{

  /* MCU Configuration--------------------------------------------------------*/

  /* Reset of all peripherals, Initializes the Flash interface and the Systick. */
  HAL_Init();

  /* Configure the system clock */
  SystemClock_Config();

  /* Initialize all configured peripherals */
  MX_GPIO_Init();
  MX_DMA_Init();
  MX_ADC1_Init();
  MX_TIM1_Init();
  MX_USART2_UART_Init();
  MX_SPI1_Init();
  MX_SPI2_Init();
  /* USER CODE BEGIN 2 */

  /* ADC self-calibration — recommended for F103 before first DMA conversion */
  HAL_ADCEx_Calibration_Start(&hadc1);

  /* Start continuous ADC→DMA: fills adc_buf[0]=BATT, [1]=MCU_TEMP forever  */
  HAL_ADC_Start_DMA(&hadc1, (uint32_t *)adc_buf, 2);

  /* Enable DWT cycle counter — 32-bit, 64 MHz, wraps every ~67 s. */
  CoreDebug->DEMCR |= CoreDebug_DEMCR_TRCENA_Msk;
  DWT->CYCCNT = 0;
  DWT->CTRL  |= DWT_CTRL_CYCCNTENA_Msk;

  /* ESC PWM output — TIM1_CH3 (PA10), 1 MHz counter (PSC=63, ARR=19999)
     gives a 20 ms (50 Hz) period with the CCR value directly in µs, so it
     matches the standard 1000–2000 µs RC/ESC pulse convention. Starts at
     1000 µs (0 % throttle / ESC armed-and-idle) before the RTOS takes over. */
  HAL_TIM_PWM_Start(&htim1, TIM_CHANNEL_3);
  __HAL_TIM_SET_COMPARE(&htim1, TIM_CHANNEL_3, 1000U);

  /* Start UART2 RX DMA with IDLE detection — fires callback on each command  */
  HAL_UARTEx_ReceiveToIdle_DMA(&huart2, rx_dma_buf, RX_BUF_SIZE);
  __HAL_DMA_DISABLE_IT(huart2.hdmarx, DMA_IT_HT); /* suppress half-transfer */

  /* Boot banner — blocking TX before RTOS scheduler starts                   */
  HAL_UART_Transmit(&huart2, (uint8_t *)"JET ECU V1.0 Ready\r\n", 20, 100);

  /* USER CODE END 2 */

  /* Init scheduler */
  osKernelInitialize();

  /* USER CODE BEGIN RTOS_MUTEX */
  uart_tx_mutex = osMutexNew(NULL);
  /* USER CODE END RTOS_MUTEX */

  /* USER CODE BEGIN RTOS_SEMAPHORES */
  uart_cmd_sem = osSemaphoreNew(1, 0, NULL);   /* binary, starts locked */
  /* USER CODE END RTOS_SEMAPHORES */

  /* USER CODE BEGIN RTOS_TIMERS */
  /* start timers, add new ones, ... */
  /* USER CODE END RTOS_TIMERS */

  /* USER CODE BEGIN RTOS_QUEUES */
  /* add queues, ... */
  /* USER CODE END RTOS_QUEUES */

  /* Create the thread(s) */
  /* creation of defaultTask */
  defaultTaskHandle = osThreadNew(StartDefaultTask, NULL, &defaultTask_attributes);

  /* USER CODE BEGIN RTOS_THREADS */
  /* 256×4=1024-byte stacks: snprintf+uart_send+FreeRTOS context save need ~500 bytes */
  static const osThreadAttr_t thr_attr = { .name="ThrottleTask",  .stack_size=256*4, .priority=osPriorityAboveNormal };
  static const osThreadAttr_t volt_attr= { .name="VoltageTask",   .stack_size=256*4, .priority=osPriorityNormal      };
  static const osThreadAttr_t fet_attr = { .name="FETReportTask", .stack_size=256*4, .priority=osPriorityNormal      };
  static const osThreadAttr_t rx_attr  = { .name="SerialRxTask",  .stack_size=256*4, .priority=osPriorityHigh        };

  throttleTaskHandle  = osThreadNew(ThrottleTask,  NULL, &thr_attr);
  voltageTaskHandle   = osThreadNew(VoltageTask,   NULL, &volt_attr);
  fetReportTaskHandle = osThreadNew(FETReportTask, NULL, &fet_attr);
  serialRxTaskHandle  = osThreadNew(SerialRxTask,  NULL, &rx_attr);
  /* USER CODE END RTOS_THREADS */

  /* USER CODE BEGIN RTOS_EVENTS */
  /* add events, ... */
  /* USER CODE END RTOS_EVENTS */

  /* Start scheduler */
  osKernelStart();

  /* We should never get here as control is now taken by the scheduler */

  /* Infinite loop */
  /* USER CODE BEGIN WHILE */
  while (1)
  {
    /* USER CODE END WHILE */

    /* USER CODE BEGIN 3 */
  }
  /* USER CODE END 3 */
}

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
/* USER CODE BEGIN 4 */

/* ── UART helpers ─────────────────────────────────────────────────────────
   uart_send() acquires a mutex (one sender at a time) then calls the
   blocking HAL_UART_Transmit.  At 115200 baud the longest message is ~4 ms;
   FreeRTOS will time-slice other tasks during that window.  The blocking
   approach is simpler and more reliable than DMA TX + semaphore because it
   avoids the race where DMA completes before osSemaphoreAcquire is reached
   and the risk of semaphore corruption from a stack overflow in the task.    */

static void uart_send(const char *str)
{
    uint16_t len = (uint16_t)strlen(str);
    if (len == 0) return;
    osMutexAcquire(uart_tx_mutex, osWaitForever);
    HAL_UART_Transmit(&huart2, (uint8_t *)str, len, HAL_MAX_DELAY);
    osMutexRelease(uart_tx_mutex);
}

/* Called from DMA IRQ on IDLE line or buffer full.
   Copies received bytes to rx_cmd, signals SerialRxTask, re-arms DMA.       */
void HAL_UARTEx_RxEventCallback(UART_HandleTypeDef *huart, uint16_t Size)
{
    if (huart->Instance == USART2 && Size > 0 && Size < RX_BUF_SIZE) {
        memcpy(rx_cmd, rx_dma_buf, Size);
        rx_cmd[Size] = '\0';
        osSemaphoreRelease(uart_cmd_sem);
        HAL_UARTEx_ReceiveToIdle_DMA(&huart2, rx_dma_buf, RX_BUF_SIZE);
        __HAL_DMA_DISABLE_IT(huart2.hdmarx, DMA_IT_HT);
    }
}

/* ── RC PWM — direct GPIO polling, equivalent to Arduino pulseIn() ────────
   Waits for a HIGH pulse on PA0 within timeout_us microseconds.
   Uses DWT cycle counter (enabled in USER CODE BEGIN 2, 64 cycles = 1 µs).
   A shared deadline across all three phases means total wait ≤ timeout_us.   */

static uint32_t pulseIn_us(GPIO_TypeDef *port, uint16_t pin, uint32_t timeout_us)
{
    uint32_t deadline = DWT->CYCCNT + timeout_us * 64U;
    /* if pin is already HIGH, wait for it to go LOW first (skip current pulse) */
    while (HAL_GPIO_ReadPin(port, pin) == GPIO_PIN_SET)
        if ((int32_t)(DWT->CYCCNT - deadline) >= 0) return 0;
    /* wait for rising edge */
    while (HAL_GPIO_ReadPin(port, pin) == GPIO_PIN_RESET)
        if ((int32_t)(DWT->CYCCNT - deadline) >= 0) return 0;
    uint32_t rise = DWT->CYCCNT;
    /* measure until falling edge */
    while (HAL_GPIO_ReadPin(port, pin) == GPIO_PIN_SET)
        if ((int32_t)(DWT->CYCCNT - deadline) >= 0) return 0;
    return (DWT->CYCCNT - rise) / 64U;
}

/* ── RC calibration helper ────────────────────────────────────────────────
   Directly measures n pulses (25 ms timeout each) — matches Arduino samplePW().
   Called from SerialRxTask; blocks up to n × (25 ms + 50 ms) ≈ 1.5 s.       */

static uint32_t sample_rc_pw(uint8_t n)
{
    uint32_t sum = 0; uint8_t cnt = 0;
    for (uint8_t i = 0; i < n; i++) {
        uint32_t pw = pulseIn_us(GPIOA, GPIO_PIN_0, 25000U);
        if (pw >= 900U && pw <= 2100U) { sum += pw; cnt++; }
        osDelay(50);
    }
    return cnt ? (sum / cnt) : 0U;
}

/* ── Task: ThrottleTask (200 ms) ──────────────────────────────────────────
   Spike filter: reject any jump > RC_MAX_STEP µs.
   Signal-loss: if no valid pulse for RC_TIMEOUT_MS, output 0 %.
   Output: THR: xxx\r\n                                                       */

void ThrottleTask(void *arg)
{
    char buf[32];
    for (;;) {
        uint32_t pw = pulseIn_us(GPIOA, GPIO_PIN_0, 50000U);

        if (pw >= 900U && pw <= 2100U) {
            uint32_t delta = (pw > rc_last_pw) ? (pw - rc_last_pw) : (rc_last_pw - pw);
            if (delta <= RC_MAX_STEP || rc_last_pw == 1500U) {
                rc_last_pw       = pw;
                rc_last_valid_ms = osKernelGetTickCount();
            }
        }

        if ((osKernelGetTickCount() - rc_last_valid_ms) > RC_TIMEOUT_MS)
            rc_last_pw = 1500U;

        uint32_t thr = 0;
        if (rc_pw_min < rc_pw_max) {
            if (rc_last_pw <= rc_pw_min) {
                thr = 0;
            } else if (rc_last_pw >= rc_pw_max) {
                thr = 100;
            } else {
                thr = (rc_last_pw - rc_pw_min) * 100U / (rc_pw_max - rc_pw_min);
            }
        }

        snprintf(buf, sizeof(buf), "THR: %lu\r\n", thr);
        uart_send(buf);

        /* ESC PWM output — throttle % mapped directly to the 1000–2000 µs
           RC/ESC pulse convention (0 % = 1000 µs, 100 % = 2000 µs).        */
        uint32_t pwm_us = 1000U + (thr * 1000U) / 100U;
        __HAL_TIM_SET_COMPARE(&htim1, TIM_CHANNEL_3, pwm_us);
        snprintf(buf, sizeof(buf), "PWM: %lu\r\n", thr);
        uart_send(buf);

        osDelay(200);
    }
}

/* ── Task: VoltageTask (500 ms batt, 1000 ms MCU temp) ───────────────────
   ADC DMA buffer read directly — no lock needed (16-bit atomic read, and
   small timing skew is irrelevant at these sample rates).

   Integer arithmetic throughout — avoids needing -u _printf_float linker flag.

   Battery divider: R1=39kΩ, R2=5.6kΩ → ratio = 44600/5600
   Calibration factor: 9905/10000 (≈ 0.9905)
   All voltages in mV, formatted with manual decimal split.

   MCU temp: V25=1580 mV (chip-calibrated), slope=4.3 mV/°C
   temp×10 = ((1580 - vt_mv) × 100) / 43 + 250                              */

void VoltageTask(void *arg)
{
    char    buf[64];
    uint8_t mcu_cnt = 0;

    for (;;) {
        /* 256-sample average with 1 ms between reads — 4x the original 64-sample
           window, which halves report-to-report ADC jitter (~sqrt(4)) without
           adding any cross-report lag (no memory carried between reports, so a
           real voltage change still shows up on the very next report).
           Total: 256 ms sampling + osDelay(500) ≈ 756 ms per voltage report.  */
        uint32_t sum = 0;
        for (uint16_t i = 0; i < 256; i++) {
            sum += adc_buf[0];
            osDelay(1);
        }
        uint16_t raw  = (uint16_t)(sum / 256U);

        /* V_ADC at divider output — kept for display and future diagnostics */
        uint32_t vadc = ((uint32_t)raw * 3300U) / 4095U;

        /* Battery voltage via direct two-point linear interpolation between
           VBATT_RAW_LO/MV_LO and VBATT_RAW_HI/MV_HI (see USER CODE BEGIN PD).
           raw ≤ VBATT_RAW_FLOOR means no battery connected → clamp to 0.    */
        uint32_t vbat = 0;
        if (raw > VBATT_RAW_FLOOR) {
            int32_t v = (int32_t)VBATT_MV_LO
                      + ((int32_t)raw - (int32_t)VBATT_RAW_LO)
                        * ((int32_t)VBATT_MV_HI - (int32_t)VBATT_MV_LO)
                        / ((int32_t)VBATT_RAW_HI - (int32_t)VBATT_RAW_LO);
            vbat = (v > 0) ? (uint32_t)v : 0;
        }

        snprintf(buf, sizeof(buf),
                 "Raw: %u\tV_ADC: %lu.%03lu V\tV_BATT: %lu.%02lu V\r\n",
                 raw,
                 vadc / 1000UL, vadc % 1000UL,
                 vbat / 1000UL, (vbat % 1000UL) / 10UL);
        uart_send(buf);

        /* MCU internal temperature — every second (every 2nd cycle) */
        if (++mcu_cnt >= 2) {
            mcu_cnt = 0;
            uint16_t rt   = adc_buf[1];
            int32_t vt_mv = ((int32_t)rt * 3300L) / 4095L;
            int32_t t10   = (((1580L - vt_mv) * 100L) / 43L) + 250L;
            snprintf(buf, sizeof(buf), "MCU: %ld.%ld C\r\n",
                     t10 / 10L, (t10 < 0 ? -t10 : t10) % 10L);
            uart_send(buf);
        }

        osDelay(500);
    }
}

/* ── Task: FETReportTask (200 ms) ─────────────────────────────────────────
   Reads actual GPIO output state via HAL_GPIO_ReadPin (reads ODR, atomic).
   Output: FET:x,x,x,x,x,x\r\n                                               */

void FETReportTask(void *arg)
{
    char buf[24];
    for (;;) {
        snprintf(buf, sizeof(buf), "FET:%u,%u,%u,%u,%u,%u\r\n",
                 (unsigned)HAL_GPIO_ReadPin(GPIOB, FET_PIN[0]),
                 (unsigned)HAL_GPIO_ReadPin(GPIOB, FET_PIN[1]),
                 (unsigned)HAL_GPIO_ReadPin(GPIOB, FET_PIN[2]),
                 (unsigned)HAL_GPIO_ReadPin(GPIOB, FET_PIN[3]),
                 (unsigned)HAL_GPIO_ReadPin(GPIOB, FET_PIN[4]),
                 (unsigned)HAL_GPIO_ReadPin(GPIOB, FET_PIN[5]));
        uart_send(buf);
        osDelay(200);
    }
}

/* ── Task: SerialRxTask (event-driven, high priority) ─────────────────────
   Waits on uart_cmd_sem released by HAL_UARTEx_RxEventCallback.

   Commands:
     FETn:v        set FET n (1-6) to v (0|1)
     CAL_CENTER    sample 20 readings at stick center → sets rc_pw_min
     CAL_FULL      sample 20 readings at full throw   → sets rc_pw_max
     CAL_RESET     clear calibration, throttle returns 0 until recal          */

void SerialRxTask(void *arg)
{
    char cmd[RX_BUF_SIZE];
    char resp[32];

    for (;;) {
        osSemaphoreAcquire(uart_cmd_sem, osWaitForever);

        strncpy(cmd, rx_cmd, RX_BUF_SIZE - 1);
        cmd[RX_BUF_SIZE - 1] = '\0';

        /* Strip CR/LF */
        for (int i = 0; cmd[i]; i++)
            if (cmd[i] == '\r' || cmd[i] == '\n') { cmd[i] = '\0'; break; }

        /* FET_ALL:v — set all 6 FETs HIGH (v=1) or LOW (v=0) */
        if (strncmp(cmd, "FET_ALL:", 8) == 0) {
            GPIO_PinState st = (cmd[8] == '1') ? GPIO_PIN_SET : GPIO_PIN_RESET;
            for (int i = 0; i < 6; i++)
                HAL_GPIO_WritePin(GPIOB, FET_PIN[i], st);
            uart_send(cmd[8]=='1' ? "FET_ALL:1\r\n" : "FET_ALL:0\r\n");
        }
        /* FETn:v — set single FET */
        else if (cmd[0]=='F' && cmd[1]=='E' && cmd[2]=='T' &&
            cmd[3] >= '1' && cmd[3] <= '6' && cmd[4] == ':') {
            int n = cmd[3] - '1';
            HAL_GPIO_WritePin(GPIOB, FET_PIN[n],
                              cmd[5] == '1' ? GPIO_PIN_SET : GPIO_PIN_RESET);
        }
        /* CAL_CENTER */
        else if (strncmp(cmd, "CAL_CENTER", 10) == 0) {
            uint32_t pw = sample_rc_pw(10);
            rc_pw_min = pw; rc_pw_max = 0;
            snprintf(resp, sizeof(resp), "CAL_CENTER:%lu\r\n", pw);
            uart_send(resp);
        }
        /* CAL_FULL */
        else if (strncmp(cmd, "CAL_FULL", 8) == 0) {
            uint32_t pw = sample_rc_pw(10);
            rc_pw_max = pw;
            snprintf(resp, sizeof(resp), "CAL_FULL:%lu\r\n", pw);
            uart_send(resp);
        }
        /* CAL_RESET */
        else if (strncmp(cmd, "CAL_RESET", 9) == 0) {
            rc_pw_min = 0U; rc_pw_max = 0U; rc_last_pw = 1500U;
            uart_send("CAL_RESET:OK\r\n");
        }
    }
}

/* USER CODE END 4 */

/* USER CODE BEGIN Header_StartDefaultTask */
/**
  * @brief  Function implementing the defaultTask thread.
  * @param  argument: Not used
  * @retval None
  */
/* USER CODE END Header_StartDefaultTask */
void StartDefaultTask(void *argument)
{
  /* USER CODE BEGIN 5 */
  for (;;)
      osDelay(1000);
  /* USER CODE END 5 */
}

/**
  * @brief  Period elapsed callback in non blocking mode
  * @note   This function is called  when TIM3 interrupt took place, inside
  * HAL_TIM_IRQHandler(). It makes a direct call to HAL_IncTick() to increment
  * a global variable "uwTick" used as application time base.
  * @param  htim : TIM handle
  * @retval None
  */
void HAL_TIM_PeriodElapsedCallback(TIM_HandleTypeDef *htim)
{
  if (htim->Instance == TIM3)
  {
    HAL_IncTick();
  }
}

/**
  * @brief  This function is executed in case of error occurrence.
  * @retval None
  */
void Error_Handler(void)
{
  /* USER CODE BEGIN Error_Handler_Debug */
  /* User can add his own implementation to report the HAL error return state */
  __disable_irq();
  while (1)
  {
  }
  /* USER CODE END Error_Handler_Debug */
}

#ifdef  USE_FULL_ASSERT
/**
  * @brief  Reports the name of the source file and the source line number
  *         where the assert_param error has occurred.
  * @param  file: pointer to the source file name
  * @param  line: assert_param error line source number
  * @retval None
  */
void assert_failed(uint8_t *file, uint32_t line)
{
  /* USER CODE BEGIN 6 */
  /* User can add his own implementation to report the file name and line number,
     ex: printf("Wrong parameters value: file %s on line %d\r\n", file, line) */
  /* USER CODE END 6 */
}
#endif /* USE_FULL_ASSERT */

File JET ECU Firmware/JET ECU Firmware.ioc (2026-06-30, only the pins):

Mcu.UserName=STM32F103C8Tx
PA0-WKUP.Signal=GPIO_Input
PA1.Signal=ADCx_IN1
PA10.Signal=S_TIM1_CH3
PA11.Signal=S_TIM1_CH4
PA13.Signal=SYS_JTMS-SWDIO
PA14.Signal=SYS_JTCK-SWCLK
PA2.Signal=USART2_TX
PA3.Signal=USART2_RX
PA5.GPIO_Label=TC1_SCK
PA5.Signal=SPI1_SCK
PA6.GPIO_Label=TC1_SO
PA6.Signal=SPI1_MISO
PA8.Signal=S_TIM1_CH1
PA9.Signal=S_TIM1_CH2
PB0.GPIO_Label=TC1_CS
PB0.Signal=GPIO_Output
PB12.GPIO_Label=TC2_CS
PB12.Signal=GPIO_Output
PB13.GPIO_Label=TC2_SCK
PB13.Signal=SPI2_SCK
PB14.GPIO_Label=TC2_SO
PB14.Signal=SPI2_MISO
PB4.GPIO_Label=FET_5
PB4.Signal=GPIO_Output
PB5.GPIO_Label=FET_2
PB5.Signal=GPIO_Output
PB6.GPIO_Label=FET_1
PB6.Signal=GPIO_Output
PB7.GPIO_Label=FET_6
PB7.Signal=GPIO_Output
PB8.GPIO_Label=FET_4
PB8.Signal=GPIO_Output
PB9.GPIO_Label=FET_3
PB9.Signal=GPIO_Output
PC14-OSC32_IN.GPIO_Label=RPM_IN
PC14-OSC32_IN.Signal=GPXTI14

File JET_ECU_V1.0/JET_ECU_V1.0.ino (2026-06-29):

/*
  JET ECU V1.0
  Platform : STM32 Blue Pill (STM32F103C8T6)
*/
#include <HardwareSerial.h>
#include <Adafruit_MAX31855.h>

HardwareSerial Serial2(PA3, PA2);

// ─── Thermocouple 1 (Exhaust / EGT) ───────────────────────────────────────
#define TC1_SCK PA5
#define TC1_SO  PA6
#define TC1_CS  PB0

// ─── Thermocouple 2 (Intake / Ambient) ─────────────────────────────────────
#define TC2_SCK PB13
#define TC2_SO  PB14
#define TC2_CS  PB12

// ─── Battery Voltage ────────────────────────────────────────────────────────
#define BATT_PIN    PA1
#define BATT_R1     39000.0f
#define BATT_R2     5600.0f
#define ADC_REF     3.3f
#define ADC_RES     4095.0f
#define NUM_SAMPLES 64
#define CAL_FACTOR  0.9905f

// ─── RC PWM Input (R12DS CH3) ────────────────────────────────────────────────
#define RC_PWM_PIN  PA0
#define RPM_SENSOR_PIN PC14
#define RPM_MAX        50000L
#define RC_MAX_STEP 400

// ─── RPM Sensor ─────────────────────────────────────────────────────────────
#define RPM_PIN PB11

// ─── FET Output Pins ────────────────────────────────────────────────────────
#define FET_1 PB6
#define FET_2 PB5
#define FET_3 PB9
#define FET_4 PB8
#define FET_5 PB4
#define FET_6 PB7

#define FET_1_HIGH digitalWrite(FET_1, HIGH)
#define FET_1_LOW  digitalWrite(FET_1, LOW)
#define FET_2_HIGH digitalWrite(FET_2, HIGH)
#define FET_2_LOW  digitalWrite(FET_2, LOW)
#define FET_3_HIGH digitalWrite(FET_3, HIGH)
#define FET_3_LOW  digitalWrite(FET_3, LOW)
#define FET_4_HIGH digitalWrite(FET_4, HIGH)
#define FET_4_LOW  digitalWrite(FET_4, LOW)
#define FET_5_HIGH digitalWrite(FET_5, HIGH)
#define FET_5_LOW  digitalWrite(FET_5, LOW)
#define FET_6_HIGH digitalWrite(FET_6, HIGH)
#define FET_6_LOW  digitalWrite(FET_6, LOW)

const uint8_t FET_PINS[6] = {FET_1, FET_2, FET_3, FET_4, FET_5, FET_6};

Adafruit_MAX31855 tc1(TC1_SCK, TC1_CS, TC1_SO);
Adafruit_MAX31855 tc2(TC2_SCK, TC2_CS, TC2_SO);

float         temp1       = 0;
float         temp2       = 0;
float         battVoltage = 0;

unsigned long lastTempRead    = 0;
unsigned long lastVoltRead    = 0;
unsigned long lastFETReport   = 0;
unsigned long lastRPMRead     = 0;
unsigned long lastMCUTempRead = 0;
String        serialBuf       = "";

// RC PWM calibration
static unsigned long pwMin       = 0;
static unsigned long pwMax       = 0;
static unsigned long lastPW      = 1000;
static unsigned long lastPWValid = 0;

unsigned long samplePW() {
    unsigned long sum = 0;
    int cnt = 0;
    for (int i = 0; i < 20; i++) {
        unsigned long p = pulseIn(RC_PWM_PIN, HIGH, 25000);
        if (p >= 900 && p <= 2100) { sum += p; cnt++; }
        delay(50);
    }
    return cnt > 0 ? sum / cnt : 0;
}

void handleSerial() {
    while (Serial2.available()) {
        char c = (char)Serial2.read();
        if (c == '\n') {
            serialBuf.trim();
            if (serialBuf.startsWith("FET") && serialBuf.length() >= 6 && serialBuf[4] == ':') {
                int n   = serialBuf[3] - '1';
                int val = serialBuf.substring(5).toInt();
                if (n >= 0 && n <= 5)
                    digitalWrite(FET_PINS[n], val ? HIGH : LOW);
            } else if (serialBuf == "CAL_CENTER") {
                pwMin = samplePW();
                pwMax = 0;
                Serial2.print("CAL_CENTER:"); Serial2.println(pwMin);
            } else if (serialBuf == "CAL_FULL") {
                pwMax = samplePW();
                Serial2.print("CAL_FULL:"); Serial2.println(pwMax);
            } else if (serialBuf == "CAL_RESET") {
                pwMin = 0; pwMax = 0; lastPW = 1000;
                Serial2.println("CAL_RESET:OK");
            }
            serialBuf = "";
        } else if (c != '\r') {
            serialBuf += c;
        }
    }
}

void reportFETStates() {
    Serial2.print("FET:");
    for (int i = 0; i < 6; i++) {
        Serial2.print(digitalRead(FET_PINS[i]));
        if (i < 5) Serial2.print(",");
    }
    Serial2.println();
}

uint16_t readADC_avg(uint8_t pin) {
    uint32_t sum = 0;
    for (int i = 0; i < NUM_SAMPLES; i++) {
        sum += analogRead(pin);
        delayMicroseconds(200);
    }
    return sum / NUM_SAMPLES;
}

void readMCUTemp() {
    uint16_t raw  = analogRead(ATEMP);
    float    v    = (raw / 4095.0f) * 3.3f;
    float    temp = ((1.58f - v) / 0.00430f) + 25.0f;
    Serial2.print("MCU: ");
    Serial2.print(temp, 1);
    Serial2.println(" C");
}

void readThrottle() {
    unsigned long pw = pulseIn(RC_PWM_PIN, HIGH, 25000);
    if (pw >= 900 && pw <= 2100) {
        unsigned long diff = (pw > lastPW) ? (pw - lastPW) : (lastPW - pw);
        if (diff <= RC_MAX_STEP) {
            lastPW      = pw;
            lastPWValid = millis();
        }
    }
    bool noSignal = (millis() - lastPWValid > 500);
    long thr = 0;
    if (!noSignal && pwMax > pwMin) {
        thr = map(constrain(lastPW, pwMin, pwMax), pwMin, pwMax, 0L, 100L);
        thr = constrain(thr, 0L, 100L);
    }
    Serial2.print("THR: ");
    Serial2.println(thr);
}

void setup() {
    Serial2.begin(115200);
    analogReadResolution(12);

    pinMode(FET_1, OUTPUT); digitalWrite(FET_1, LOW);
    pinMode(FET_2, OUTPUT); digitalWrite(FET_2, LOW);
    pinMode(FET_3, OUTPUT); digitalWrite(FET_3, LOW);
    pinMode(FET_4, OUTPUT); digitalWrite(FET_4, LOW);
    pinMode(FET_5, OUTPUT); digitalWrite(FET_5, LOW);
    pinMode(FET_6, OUTPUT); digitalWrite(FET_6, LOW);

    pinMode(BATT_PIN,   INPUT_ANALOG);
    pinMode(RPM_PIN,    INPUT);
    pinMode(RC_PWM_PIN, INPUT);

    if (!tc1.begin()) Serial2.println("TC1 error - check wiring");
    if (!tc2.begin()) Serial2.println("TC2 error - check wiring");

    Serial2.println("JET ECU V1.0 Ready");
}

void readTemperatures() {
    temp1 = tc1.readCelsius();
    temp2 = tc2.readCelsius();
    if (isnan(temp1)) temp1 = 0;
    if (isnan(temp2)) temp2 = 0;
    Serial2.print("TC1: "); Serial2.print(temp1, 1);
    Serial2.print(" C  |  ");
    Serial2.print("TC2: "); Serial2.print(temp2, 1);
    Serial2.println(" C");
}

void readBattVoltage() {
    uint16_t raw   = readADC_avg(BATT_PIN);
    float    v_adc = (raw / ADC_RES) * ADC_REF;
    battVoltage    = v_adc * ((BATT_R1 + BATT_R2) / BATT_R2) * CAL_FACTOR;
    Serial2.print("Raw: ");     Serial2.print(raw);
    Serial2.print("\tV_ADC: "); Serial2.print(v_adc, 3); Serial2.print(" V");
    Serial2.print("\tV_BATT: ");Serial2.print(battVoltage, 2); Serial2.println(" V");
}

void loop() {
    handleSerial();

    if (millis() - lastTempRead >= 250) {
        lastTempRead = millis();
        readTemperatures();
    }
    if (millis() - lastVoltRead >= 500) {
        lastVoltRead = millis();
        readBattVoltage();
    }
    if (millis() - lastFETReport >= 200) {
        lastFETReport = millis();
        reportFETStates();
    }
    if (millis() - lastRPMRead >= 200) {
        lastRPMRead = millis();
        readThrottle();
    }
    if (millis() - lastMCUTempRead >= 1000) {
        lastMCUTempRead = millis();
        readMCUTemp();
    }
}

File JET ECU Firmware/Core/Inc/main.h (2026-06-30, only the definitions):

#define RPM_IN_Pin GPIO_PIN_14
#define RPM_IN_GPIO_Port GPIOC
#define RPM_IN_EXTI_IRQn EXTI15_10_IRQn
#define TC1_SCK_Pin GPIO_PIN_5
#define TC1_SCK_GPIO_Port GPIOA
#define TC1_SO_Pin GPIO_PIN_6
#define TC1_SO_GPIO_Port GPIOA
#define TC1_CS_Pin GPIO_PIN_0
#define TC1_CS_GPIO_Port GPIOB
#define TC2_CS_Pin GPIO_PIN_12
#define TC2_CS_GPIO_Port GPIOB
#define TC2_SCK_Pin GPIO_PIN_13
#define TC2_SCK_GPIO_Port GPIOB
#define TC2_SO_Pin GPIO_PIN_14
#define TC2_SO_GPIO_Port GPIOB
#define FET_5_Pin GPIO_PIN_4
#define FET_5_GPIO_Port GPIOB
#define FET_2_Pin GPIO_PIN_5
#define FET_2_GPIO_Port GPIOB
#define FET_1_Pin GPIO_PIN_6
#define FET_1_GPIO_Port GPIOB
#define FET_6_Pin GPIO_PIN_7
#define FET_6_GPIO_Port GPIOB
#define FET_4_Pin GPIO_PIN_8
#define FET_4_GPIO_Port GPIOB
#define FET_3_Pin GPIO_PIN_9
#define FET_3_GPIO_Port GPIOB

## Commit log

2026-06-29 Update README files to reflect current firmware state
2026-06-30 Add STM32CubeIDE firmware and project documentation
    - JET ECU Firmware/: STM32CubeIDE project for STM32F103C8T6 (Blue Pill)
    Implements FreeRTOS firmware with battery voltage monitoring (64-sample
    averaged ADC, two-point calibration), RC throttle input (GPIO pulseIn via
    DWT, 0-100% with spike filter and GUI calibration), 6 FET outputs,
    MCU temperature sensor, and UART telemetry at 115200 baud.
    - JET_ECU_Project_Documentation.docx: full project documentation covering
    requirements, hardware, architecture, implemented features, serial protocol,
    calibration procedures, issues and resolutions, and pending work.
    [JET ECU Firmware.ioc, main.c, main.h]
2026-06-30 Add FET_ALL commands, ALL HIGH/LOW buttons, default RC cal values
    [JET ECU ver_2.1.GBL, JET ECU ver_2.1.GBO, JET ECU ver_2.1.GBP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]
2026-06-30 FET group control, GUI 2x4 layout, RC defaults, updated documentation
2026-06-30 Match ALL HIGH/LOW button size to TOGGLE button
2026-06-30 Remove unintended files from repository
    [JET ECU ver_2.1.GBL, JET ECU ver_2.1.GBO, JET ECU ver_2.1.GBP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]
2026-06-30 Exclude local design files from git tracking
    [JET ECU ver_2.1.GBL, JET ECU ver_2.1.GBO, JET ECU ver_2.1.GBP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]
2026-06-30 Remove design files from tracking - kept in .gitignore
    [JET ECU ver_2.1.GBL, JET ECU ver_2.1.GBO, JET ECU ver_2.1.GBP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]
2026-07-01 Fix battery voltage calibration for direct-supply power, reduce ADC jitter, update docs
    [main.c]
2026-07-02 Add ESC PWM output, restructure GUI layout, update battery calibration and docs

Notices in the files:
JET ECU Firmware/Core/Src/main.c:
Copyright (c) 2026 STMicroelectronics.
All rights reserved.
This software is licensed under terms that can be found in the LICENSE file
